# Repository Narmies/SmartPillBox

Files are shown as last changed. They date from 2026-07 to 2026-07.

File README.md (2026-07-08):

# 💊 SimpleMed - Smart Medicine Box (ჭკვიანი წამლების ყუთი)

ეს პროექტი არის ESP32-სა და RTC DS3231 მოდულზე ბაზირებული, ორ სლოტიანი **ჭკვიანი წამლების ყუთი**. მოწყობილობის კონფიგურაცია ხდება მარტივი ვებ-ინტერფეისის საშუალებით და ინტეგრირებული აქვს Telegram შეტყობინებების სისტემა.

## 🚀 ფუნქციები
- **ორენოვანი მხარდაჭერა:** ვებ-ინტერფეისი და Telegram შეტყობინებები მუშაობს როგორც ინგლისურ, ასევე ქართულ ენაზე.
- **სერვო ძრავების უსაფრთხო კონტროლი:** გაჭედვის საწინააღმდეგო სპეციალური კუთხეები ($50^\circ$ და $55^\circ$) და თავსახურის ავტომატური დაკეტვა 120 წამის შემდეგ.
- **RTC DS3231 დროის კონტროლი:** რეალური დროის მოდული, რომელიც ინარჩუნებს დროს დენის გათიშვის შემთხვევაშიც კი.
- **Telegram შეტყობინებები:** შეხსენება წამლის დროის მოსვლისას, დასტური მიღებისას და გაფრთხილება მოულოდნელი გათიშვის (Power Loss) შესახებ.
- **აქტიური განგაში:** წყვეტილი ხმოვანი სიგნალი (Buzzer) და LED ინდიკატორი, რომელიც ითიშება ღილაკზე ხელის დაჭერით.
- **მკურნალობის კურსის ხანგრძლივობა:** დღეების რაოდენობის განსაზღვრა (მაგ. 7 დღის შემდეგ შეხსენებები ავტომატურად ჩერდება).

## 🛠️ საჭირო კომპონენტები
- ESP32 Development Board
- Real Time Clock RTC DS3231 მოდული
- 2x SG90 სერვო ძრავი (თავსახურებისთვის)
- Buzzer (აქტიური ხმოვანი სიგნალი) და LED ნათურა
- Push Button (ღილაკი - Interrupt მხარდაჭერით)

## 📌 პინების განაწილება (Pinout)
- **Buzzer:** Pin 5
- **LED:** Pin 2
- **Button:** Pin 15 (Internal Pull-Up)
- **Servo 1 (სლოტი 1):** Pin 18
- **Servo 2 (სლოტი 2):** Pin 19
- **I2C (RTC მოდულისთვის):** ESP32-ის სტანდარტული SDA/SCL პინები

## 💻 დაყენების ინსტრუქცია
1. გახსენით `firmware/SimpleMed.ino` ფაილი Arduino IDE-ში.
2. დარწმუნდით, რომ დაინსტალირებული გაქვთ შემდეგი ბიბლიოთეკები: `UniversalTelegramBot`, `RTClib`, `ESP32Servo`.
3. კოდში `YOUR_TELEGRAM_BOT_TOKEN_HERE`-ს ნაცვლად ჩაწერეთ თქვენი ბოტის რეალური ტოკენი.
4. ჩატვირთეთ კოდი ESP32-ზე.
5. ტელეფონით ან კომპიუტერით დაუკავშირდით Wi-Fi ქსელს სახელით: **SmartPillBox-Setup**.
6. ბრაუზერში გახსენით მისამართი `192.168.4.1`, აირჩიეთ ენა, მიუთითეთ საათები, თქვენი სახლის Wi-Fi-ს მონაცემები და Telegram Chat ID.

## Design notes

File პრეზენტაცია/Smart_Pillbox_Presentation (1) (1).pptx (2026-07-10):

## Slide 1

CE490B · ილიას სახელმწიფო უნივერსიტეტი · 2026

ჭკვიანი წამლის ყუთი

Smart Pillbox — Automated Medication Reminder System

პრეზენტატორები:
ნარმინ სეიდოვა
ხამმათი აბაზოვი
აინურ ალახვერდიევა

პროექტის ხელმძღვანელები:
დავით ჩხაიძე
გიორგი მოდებაძე

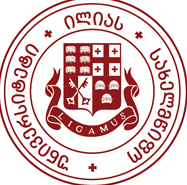
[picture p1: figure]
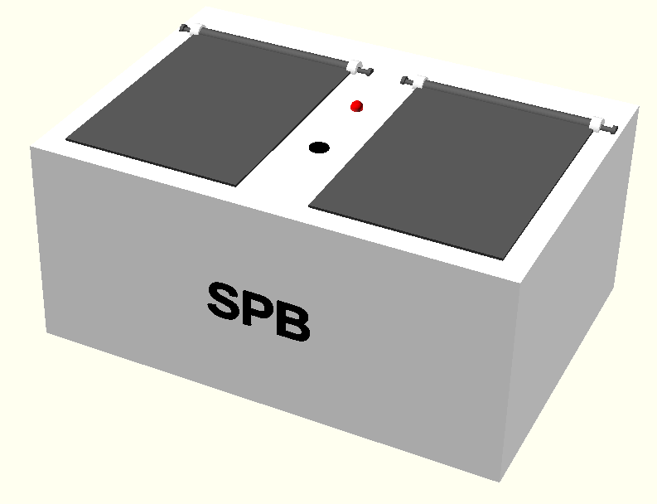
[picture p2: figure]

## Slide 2

პრობლემა

დავიწყება, რომელიც ძვირი უჯდება ჯანმრთელობას

~50%

ქრონიკული დაავადების მქონე პაციენტი არ იცავს პრეპარატის მიღების რეჟიმს.

წყარო: WHO, 2003

35–45%

ხანდაზმულ პაციენტს ავიწყდება ყოველდღიური მედიკამენტის მიღება.

წყარო: WHO, 2003

300–500$

ღირს ბაზარზე არსებული ჭკვიანი დისპენსერი — ხშირად ყოველთვიური საბონენტო გადასახადითურთ.

მაგ. MedMinder Maya, Hero Health

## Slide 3

გადაწყვეტა

ოთხი ფუნქცია, ერთი მარტივი ყუთი

ზუსტი შეხსენება

DS3231 RTC მოდული დროს ინახავს კვების გათიშვის შემთხვევაშიც კი — შეხსენება ირთვება ±1 წამის სიზუსტით.

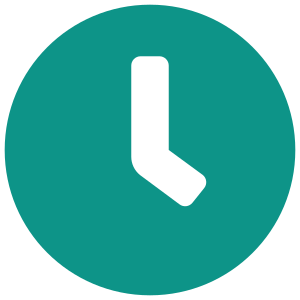
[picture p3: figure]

01

ფიზიკური წვდომა

ღილაკზე დაჭერისას სერვო-მოტორი 45°-ით ხსნის სწორ განყოფილებას — <1 წამში.

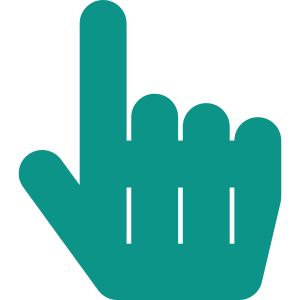
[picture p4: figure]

02

Telegram შეტყობინება

თუ დასტური არ დაფიქსირდა, მომვლელს <3 წამში ეგზავნება გამაფრთხილებელი შეტყობინება.

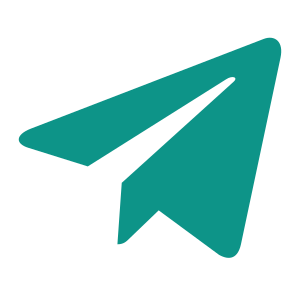
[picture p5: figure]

03

Web კონფიგურაცია

მოწყობილობა თავად ქმნის Wi-Fi ქსელს — გრაფიკის დაყენება ხდება ტელეფონის ბრაუზერიდან, აპლიკაციის გარეშე.

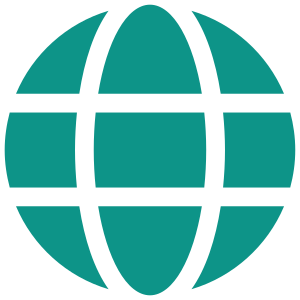
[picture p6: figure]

04

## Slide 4

ინტერფეისი

დაყენება ორ წუთში, აპლიკაციის გარეშე

1

2

01

02

დაუკავშირდით ყუთის ქსელს

მოწყობილობა ჩართვისას თავად ქმნის Wi-Fi ქსელს — „SmartPillBox-Setup“ — ხილვადია ტელეფონის Wi-Fi სიაში.

აირჩიეთ ენა

Web გვერდი იხსნება ავტომატურად (captive portal) და მხარს უჭერს ქართულ და ინგლისურ ენებს.

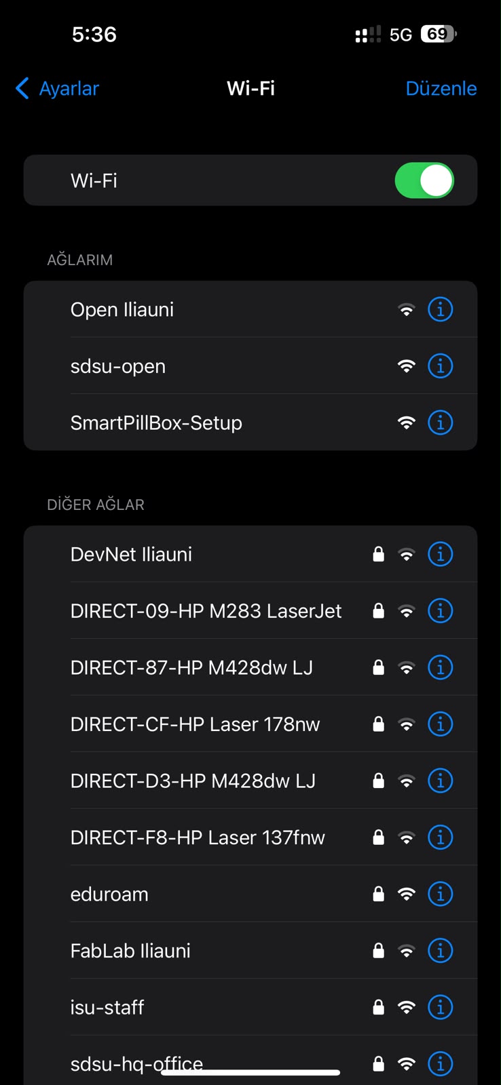
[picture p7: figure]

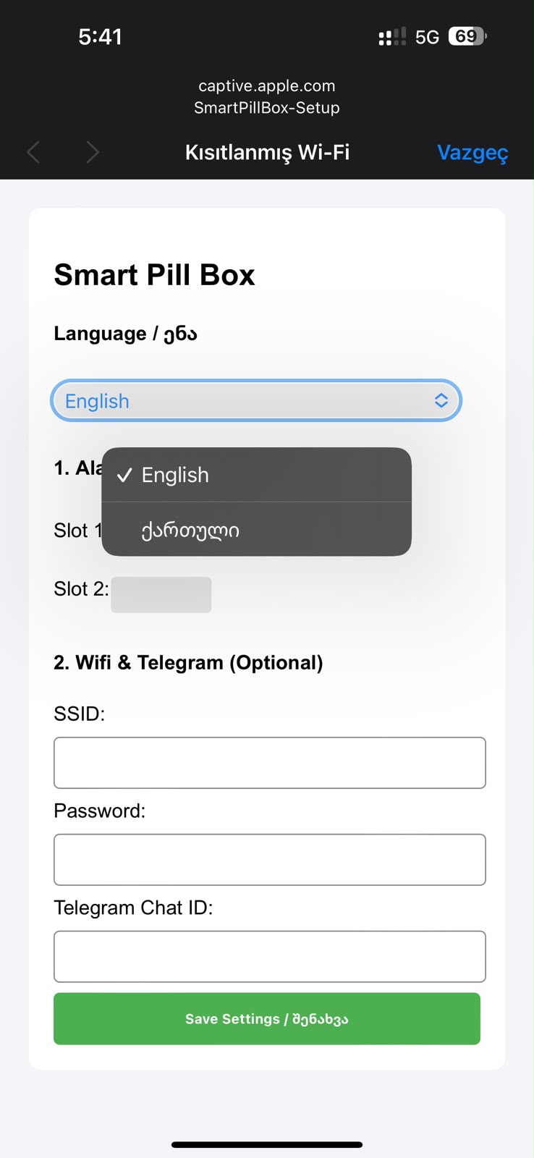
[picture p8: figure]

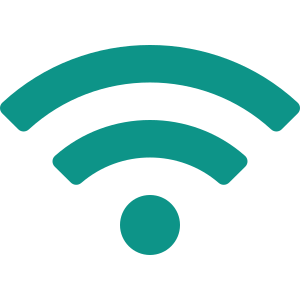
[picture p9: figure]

→

03

04

დააყენეთ დრო და Telegram

შეიყვანეთ ბოლქვის დროის გრაფიკი, სახლის Wi-Fi და Telegram Chat ID მომვლელის შესატყობინებლად.

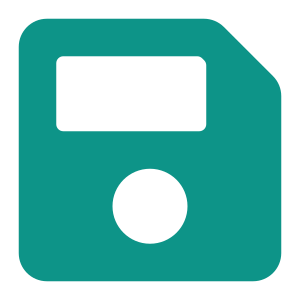
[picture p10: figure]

შეინახეთ და დაივიწყეთ

პარამეტრები ინახება EEPROM-ში და გადარჩება კვების გათიშვის შემთხვევაშიც.

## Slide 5

მუშაობის პრინციპი

ერთი ციკლი, ნაბიჯ-ნაბიჯ

დროის შემოწმება

ESP32 ყოველ წამში კითხულობს დროს DS3231 RTC-იდან (I²C) და ადარებს გრაფიკს.

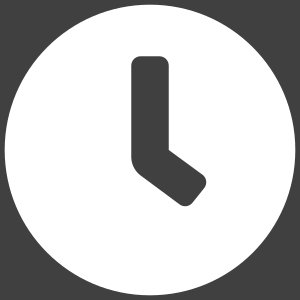
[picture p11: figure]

შეხსენების გააქტიურება

დროის დამთხვევისას ირთვება ხმოვან-ვიზუალური სიგნალი — ბუზერი და წითელი LED.

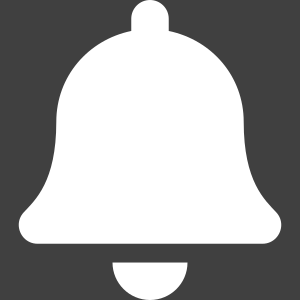
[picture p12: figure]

პაციენტის დასტური

პაციენტი აჭერს ღილაკს, სიგნალი ჩერდება და სერვო ხსნის შესაბამის განყოფილებას.

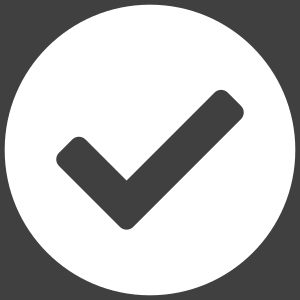
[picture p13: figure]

დასტურის გაცემა

Telegram Bot მომვლელს უგზავნის დადასტურების შეტყობინებას მიღების შესახებ.

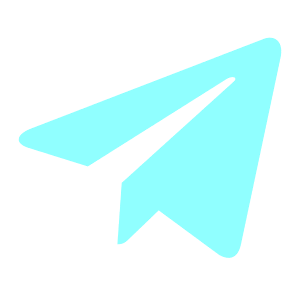
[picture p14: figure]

გამოტოვების შემთხვევა

2 წუთის განმავლობაში დაუდასტურებლობისას სისტემა აგზავნის გამაფრთხილებელ შეტყობინებას.

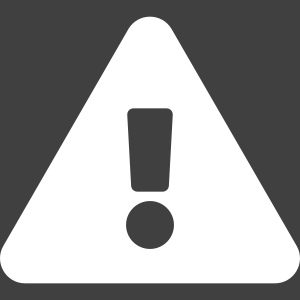
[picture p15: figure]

→

→

→

→

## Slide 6

კომპონენტების ელექტრული შეერთების სქემა

RTC

I²C · SDA/SCL

Buzzer

GPIO 25

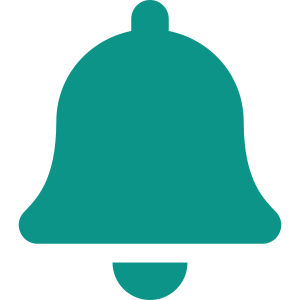
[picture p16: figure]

SG90 სერვო A

DS3231 RTC

GPIO 13 · PWM

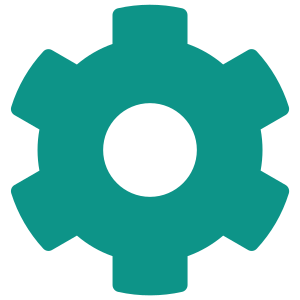
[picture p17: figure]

ESP32 DevKit

38-pin · Dual-core

LED (წითელი)

Buzzer

GPIO 26

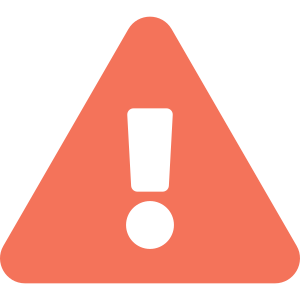
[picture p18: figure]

SG90 სერვო B

GPIO 14 · PWM

Wi-Fi / Telegram

HTTPS Cloud API

Push Button

GPIO 27

5V / 2A კვება

USB Power

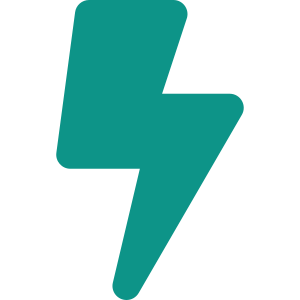
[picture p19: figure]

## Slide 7

საწარმო ნახაზი

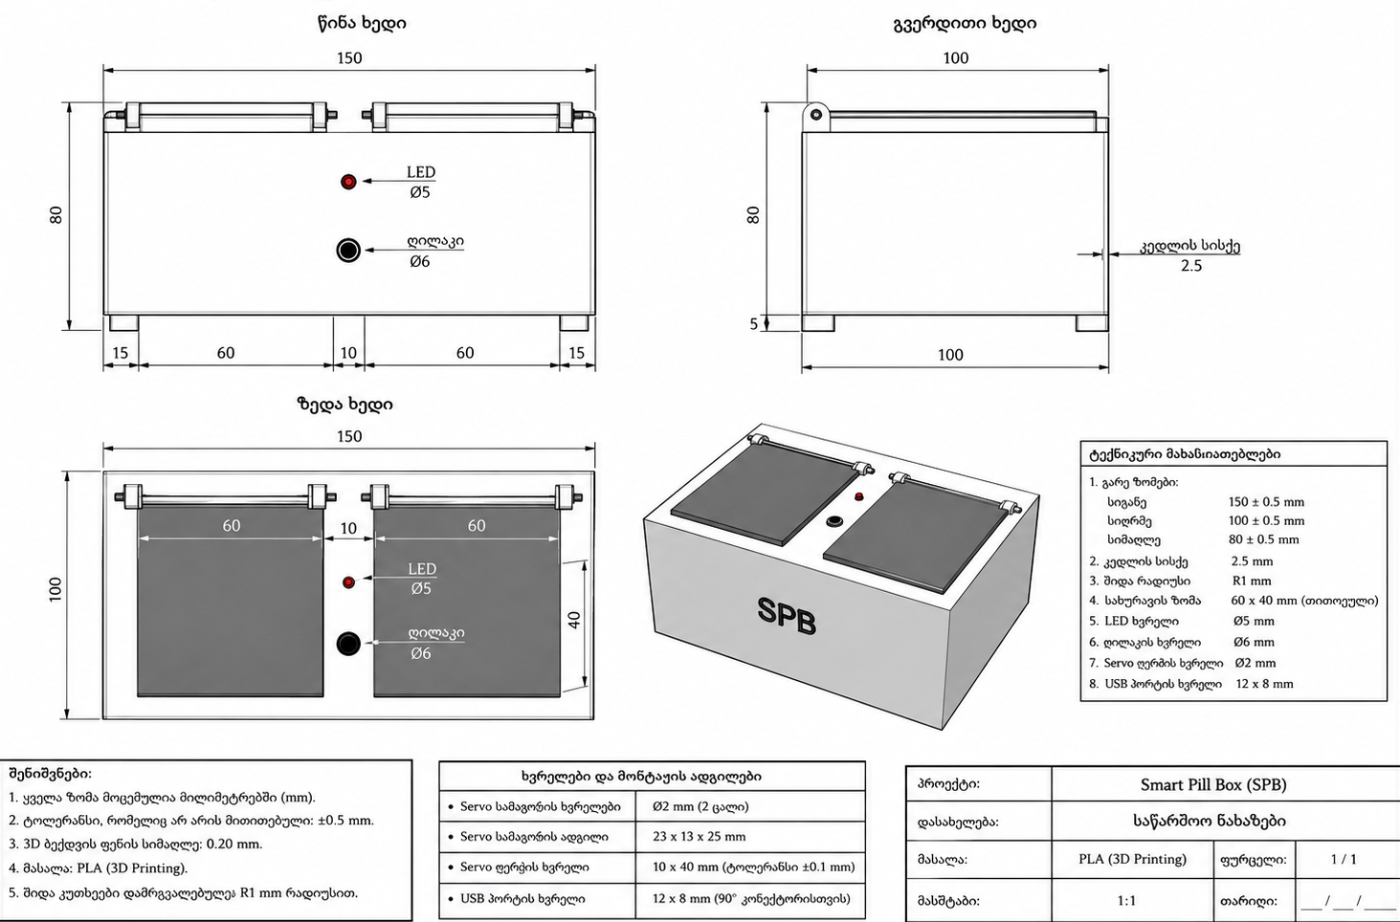
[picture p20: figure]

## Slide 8

გუნდი

CE490B გუნდი

პროექტი განხორციელდა სამკაციანი გუნდის მიერ

ნარმინ სეიდოვა

Lead Software Engineer

ESP32 ფირმვეარისა და არქიტექტურის შემუშავება, Wi-Fi AP კონფიგურაცია, EEPROM ლოგიკა, Web ინტერფეისი და Telegram Bot API ინტეგრაცია. გადაჭრა სერვოს PWM jitter პრობლემა LEDC ტაიმერით.

ხამათი აბაზოვი

Hardware & Prototyping Engineer

კორპუსის 3D მოდელირება და CAD დიზაინი, ელექტრული სქემები და ფიზიკური აწყობა. კვების ბიუჯეტის ანალიზი და პროტოტიპის მექანიკური ტესტირება.

აინურ ალახვერდიევა

Systems Analyst & Documentation Manager

ტექნიკური დოკუმენტაცია, ბლოკ-სქემები და ალგორითმები, ბაზრის ანალიზი, BOM ბიუჯეტი, განტის დიაგრამა, სტანდარტების შესაბამისობა.

ნს

ხა

აა

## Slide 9

SMART PILLBOX

მადლობა ყურადღებისთვის

ნარმინ სეიდოვა · აინურ ალახვერდიევა · ხამათი აბაზოვი

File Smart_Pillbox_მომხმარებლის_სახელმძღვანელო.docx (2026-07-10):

SMARTPILLBOX

ჭკვიანი წამლის ყუთი

მომხმარებლის სახელმძღვანელო

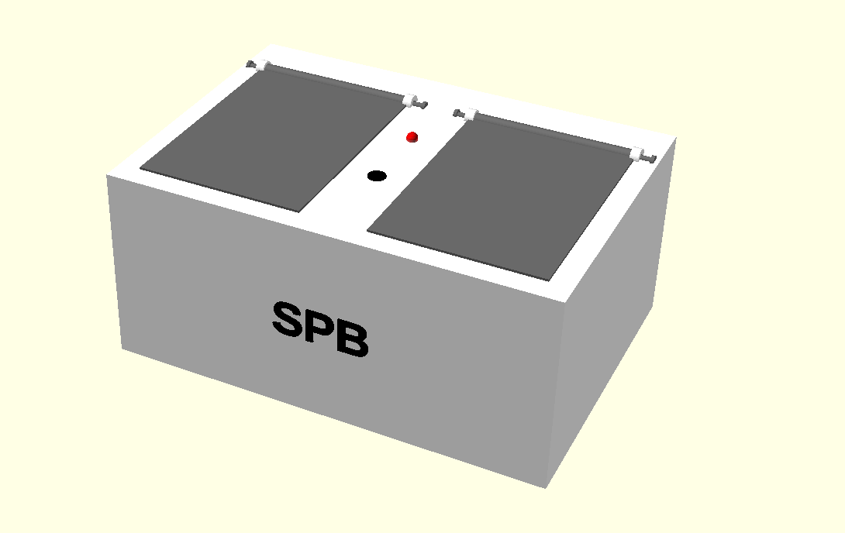
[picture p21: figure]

CE490B — Smart Pillbox (SPB) პროექტი

ილიას სახელმწიფო უნივერსიტეტი, თბილისი, 2026

# 1. შესავალი

Smart Pillbox (SPB) არის ორ-განყოფილებიანი ჭკვიანი წამლის ყუთი, რომელიც შექმნილია მედიკამენტების მიღების გრაფიკის დასაცავად — განსაკუთრებით ხანდაზმული პაციენტებისა და ქრონიკული დაავადებების მქონე პირებისთვის. მოწყობილობა ESP32 მიკროკონტროლერზეა დაფუძნებული და აერთიანებს ოთხ ძირითად ფუნქციას.

- ავტომატური ხმოვანი და ვიზუალური შეხსენება წინასწარ განსაზღვრულ დროს.
- ფიზიკური წვდომის კონტროლი — განყოფილება იხსნება მხოლოდ ღილაკზე დაჭერის შემდეგ.
- Telegram Bot შეტყობინებები მომვლელისთვის — მიღების ან გამოტოვების შესახებ, რეალურ დროში.
- Wi-Fi ვებ-ინტერფეისი გრაფიკის მარტივი კონფიგურაციისთვის, დამატებითი აპლიკაციის გარეშე.

წინამდებარე სახელმძღვანელო გიხსნით მოწყობილობის პირველად გამართვას, ყოველდღიურ გამოყენებას, მოვლას და ხშირად წამოჭრილი პრობლემების მოგვარებას.

# 2. კომპლექტის შემადგენლობა

- Smart Pillbox მოწყობილობა (ორი განყოფილებით)
- 5V / 2A USB კვების ადაპტერი და USB კაბელი

შემოწმებული USB კვების ადაპტერი აუცილებელია სტაბილური მუშაობისთვის — მინიმუმ 5V/2A.

# 3. მოწყობილობის აღწერა

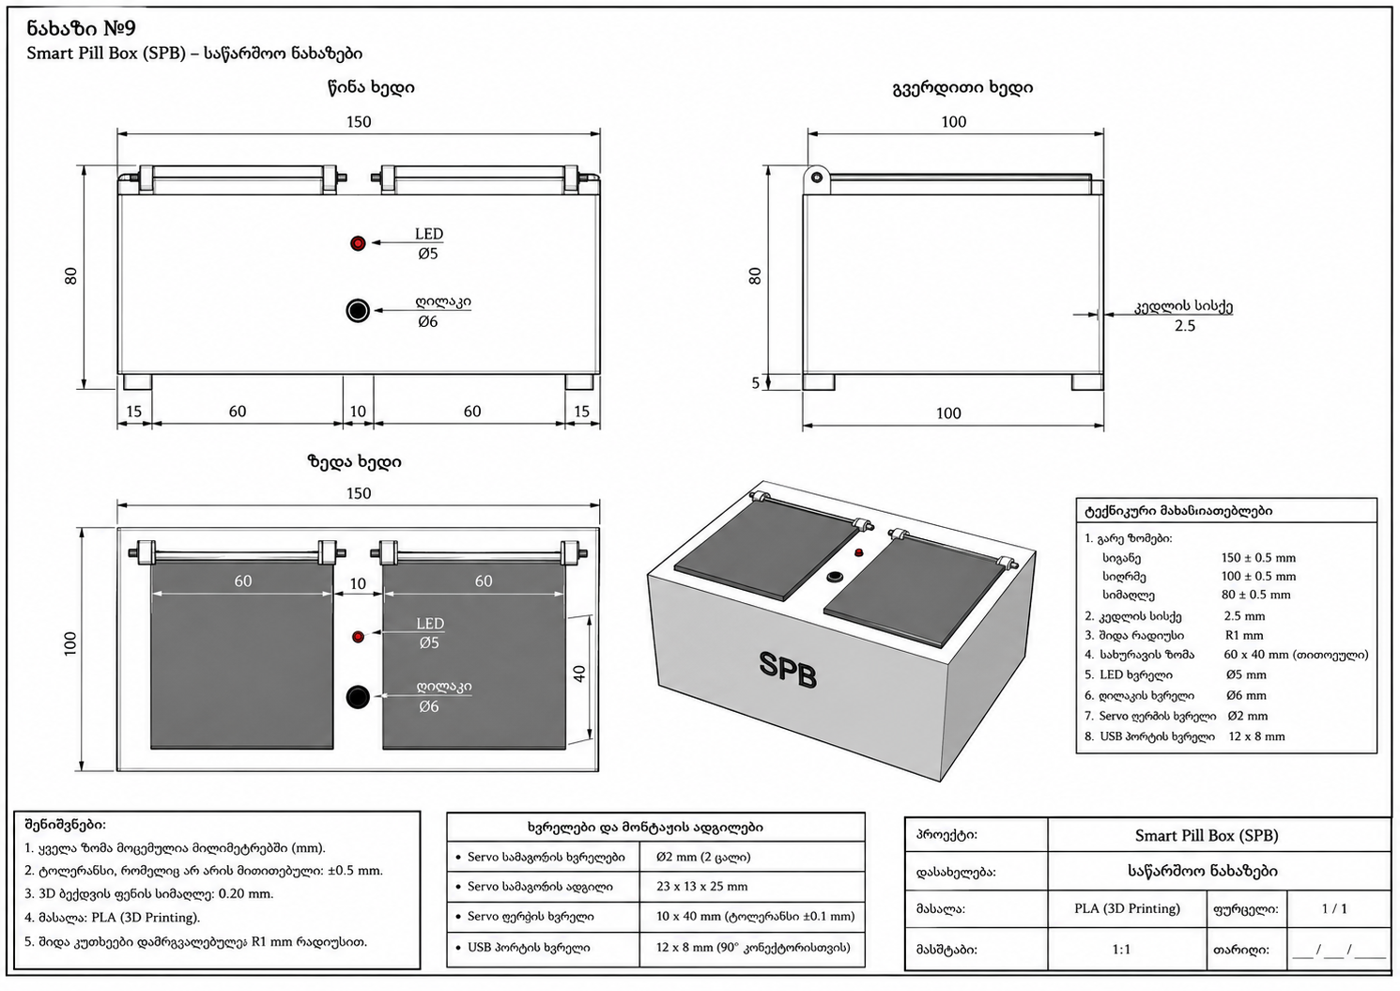
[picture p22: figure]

სურ. 1 — Smart Pillbox-ის კორპუსის აღნაგობა და ზომები

## წინა პანელი

- ორი დახურვადი განყოფილება — მარცხენა (განყოფილება 1) და მარჯვენა (განყოფილება 2), თითოეული საკუთარი სერვო-საკეტით.
- წითელი LED ინდიკატორი — ანთებულია შეხსენების დროს.
- დასტურის ღილაკი — გამოიყენება შეხსენების დასადასტურებლად და გახსნის გასააქტიურებლად.
- ჩაშენებული ხმოვანი სიგნალიზატორი (buzzer) — გაისმის შეხსენების დროს.

## გვერდითი პანელი

- USB კვების პორტი (5V).

# 4. პირველადი გამართვა

## 4.1 კვების მიერთება

1. მიაერთეთ USB კაბელი მოწყობილობასა და 5V/2A ადაპტერს შორის.
2. ჩართეთ ადაპტერი ელქსელში. წამიერად აინთება LED, რაც სისტემის გაშვებას მიანიშნებს.

პირველი ჩართვისას, თუ მოწყობილობას ჯერ არ აქვს შენახული Wi-Fi ქსელის მონაცემები, ის ავტომატურად გადადის კონფიგურაციის რეჟიმში.

## 4.2 დაკავშირება Wi-Fi კონფიგურაციის რეჟიმში

1. თქვენს ტელეფონზე ან კომპიუტერზე გახსენით Wi-Fi ქსელების სია.
2. მოძებნეთ და დაუკავშირდით ქსელს სახელით "SmartPillbox-Setup".
3. დაკავშირების შემდეგ გახსენით ბრაუზერი — კონფიგურაციის გვერდი ავტომატურად უნდა გაიხსნას;

4.3 გრაფიკისა და Telegram-ის მორგება ვებ-გვერდზე

კონფიგურაციის გვერდზე შეავსეთ შემდეგი ველები:

- "განყოფილება 1" — პირველი დოზის მიღების დრო (სთ:წთ).
- "განყოფილება 2" — მეორე დოზის მიღების დრო (სთ:წთ).
- "Telegram" — მომვლელის Chat ID.
1. შევსების შემდეგ დააჭირეთ ღილაკს "შენახვა".
2. მოწყობილობა შეინახავს პარამეტრებს და გადაერთვება ჩვეულებრივ სამუშაო რეჟიმში.

მომხმარებელი Telegram-ში შედის ძიების (Search) განყოფილებაში, ეძებს SmartPillBox ბოტს და აჭერს Start-ს. ამის შემდეგ მოწყობილობის Wi-Fi პარამეტრებში უთითებს სახლის Wi-Fi ქსელის სახელს, პაროლს და საკუთარ Telegram Chat ID-ს.

თუ ეს მონაცემები შეიყვანს, SmartPillBox დაუკავშირდება ინტერნეტს და Telegram-ის საშუალებით მომხმარებელს გაუგზავნის შეტყობინებებს წამლის მიღების დროისა და სხვა მოვლენების შესახებ.

თუ მომხმარებელი Wi-Fi-ს ან Telegram Chat ID-ს არ შეიყვანს, მოწყობილობა მაინც სრულად ფუნქციონირებს ლოკალურ რეჟიმში (Local Mode). ამ შემთხვევაში წამლის შეხსენებები განხორციელდება მხოლოდ თავად მოწყობილობაზე (ხმოვანი ან ვიზუალური სიგნალებით), ხოლო Telegram-ზე შეტყობინებები არ გაიგზავნება და ინტერნეტთან კავშირი საჭირო არ იქნება.

## 4.4 სახლის Wi-Fi ქსელთან დაკავშირება

იმ შემთხვევაში, თუ მოწყობილობას სურთ სახლის ინტერნეტ ქსელთან დაკავშირება (საჭიროა Telegram შეტყობინებებისთვის), საკონფიგურაციო გვერდზე მიუთითეთ სახლის Wi-Fi ქსელის სახელი (SSID) და პაროლი. ამის შემდეგ მოწყობილობა გადაირთვება მითითებულ ქსელზე და აღარ გაააქტიურებს კონფიგურაციის Access Point-ს ხელახლა ჩართვისას, სანამ შენახული ქსელი ხელმისაწვდომია.

# 5. ყოველდღიური გამოყენება

გრაფიკის კონფიგურაციის შემდეგ მოწყობილობა მუშაობს ავტომატურად. მოქმედების ციკლი შემდეგნაირად მიმდინარეობს:

1. მოწყობილობა უწყვეტად ადარებს მიმდინარე დროს შენახულ გრაფიკს.
2. დანიშნულ დროს ირთვება ხმოვანი სიგნალი და ციმციმებს წითელი LED.
3. დააჭირეთ დასტურის ღილაკს — ეს ადასტურებს, რომ თქვენ მზად ხართ მედიკამენტის მისაღებად.
4. შესაბამისი განყოფილების სერვო-საკეტი იხსნება (~1 წამში) და შეგიძლიათ ამოიღოთ მედიკამენტი.
5. 2 წუთის შემდეგ განყოფილება ავტომატურად იკეტება ხელახლა.
6. წარმატებული მიღების შესახებ Telegram შეტყობინება ეგზავნება მომვლელს.

თუ ღილაკზე დაჭერა არ მოხდა 2 წუთის განმავლობაში, სისტემა თვლის, რომ დოზა გამოტოვებულია, გამოთიშავს ხმოვან სიგნალს და მომვლელს უგზავნის გამაფრთხილებელ შეტყობინებას.

## Telegram შეტყობინებების სახეები

- სისტემის გაშვება — იგზავნება მოწყობილობის ჩართვისას ან გადატვირთვისას.
- წამლის მიღება — იგზავნება პაციენტის მიერ ღილაკზე დაჭერის შემდეგ.
- დოზის გამოტოვება — იგზავნება, თუ 2 წუთის განმავლობაში დასტური არ მოხდა.

# 6. მოვლა და შენახვა

ინტერვალი | სამუშაო
ყოველი 3 თვე | დასტურის ღილაკის ტესტირება ვებ-ინტერფეისიდან.
ყოველი 6 თვე | სერვო-მოტორის რეაგირების დროის შემოწმება — შენელება მიანიშნებს ცვეთაზე.
წელიწადში ერთხელ | RTC საათის სინქრონიზაცია Wi-Fi NTP-ის საშუალებით (საკმარისია ინტერნეტთან დაკავშირება).

კორპუსის გასუფთავებას მოახდინეთ მშრალი ან ოდნავ ნესტიანი ქსოვილით. მოერიდეთ სითხის პირდაპირ დასხმას მოწყობილობაზე.

# 7. ხშირად წამოჭრილი პრობლემები

პრობლემა | შესაძლო მიზეზი | გადაწყვეტა
ხმოვანი სიგნალი სუსტია | დაბალი PWM დონე | მიმართეთ ტექნიკურ მხარდაჭერას firmware-ის პარამეტრის კორექციისთვის.
სერვო-მოტორი ვიბრირებს გახსნისას | ძაბვის მცირე ვარდნა კვების ჩართვის დროს | დარწმუნდით, რომ იყენებთ 5V/2A (არა უფრო სუსტ) ადაპტერს.
Telegram შეტყობინება იგვიანებს ან არ მოდის | სუსტი Wi-Fi სიგნალი ან არასწორი ტოკენი | დაარეგისტრირეთ მოწყობილობა როუტერთან უფრო ახლოს; გადაამოწმეთ Telegram ტოკენი კონფიგურაციის გვერდზე.
დაზოგილი გრაფიკი დაიკარგა | მოწყობილობა არ იყო გამორთული სწორად კვების პროცესში | გრაფიკი ავტომატურად ინახება EEPROM-ში — ხელახლა შეიყვანეთ გრაფიკი ვებ-გვერდიდან.
ვერ ვუკავშირდები SmartPillbox-Setup ქსელს | მოწყობილობას უკვე აქვს შენახული სახლის Wi-Fi | დააჭირეთ და დაიჭირეთ დასტურის ღილაკი 5 წამის განმავლობაში კონფიგურაციის რეჟიმის ხელახლა გასააქტიურებლად.

# 8. უსაფრთხოების ინსტრუქციები

- გამოიყენეთ მხოლოდ თანდართული ან შესაბამისი 5V/2A CE-სერტიფიცირებული USB ადაპტერი.
- არ ჩაუშვათ მოწყობილობა წყალში და არ დატოვოთ ტენიან გარემოში.
- არ ცადოთ სერვოს მექანიზმის ხელით გატეხვა ან ძალდატანებით გახსნა. ამან შესაძლოა დააზიანოს მექანიზმი.
- მოწყობილობა განკუთვნილია მხოლოდ საშინაო, სტაციონარულ გამოყენებისთვის ოთახის ტემპერატურაზე.

9. ტექნიკური მახასიათებლები

პარამეტრი | მნიშვნელობა
მიკროკონტროლერი | ESP32 (ორბირთვიანი, ჩაშენებული Wi-Fi)
საათის მოდული | DS3231 RTC (±2 ppm სიზუსტე)
გახსნის მექანიზმი | SG90 სერვო-მოტორი ×2 (45° ბრუნვა)
კვება | 5V / 2A USB ადაპტერი (SELV)
კავშირი | Wi-Fi 2.4 GHz (IEEE 802.11), Access Point ან სახლის ქსელი
შეტყობინებები | Telegram Bot API (HTTPS)
გარეთა ზომები | 150 × 100 × 80 მმ (±0.5 მმ)
კორპუსის მასალა | PLA (3D ბეჭდვა)
შეხსენების სიზუსტე | ±1 წამი
გახსნის რეაგირების დრო | < 1 წამი
Telegram შეტყობინების დაყოვნება | < 3 წამი

# 10. მხარდაჭერა

პროექტის სრული საწყისი კოდი, ნახაზები და დამატებითი მასალები ხელმისაწვდომია პროექტის GitHub რეპოზიტორიაში:

GitHub Link (https://github.com/Narmies/SmartPillBox)

Smart Pillbox — მომხმარებლის სახელმძღვანელო

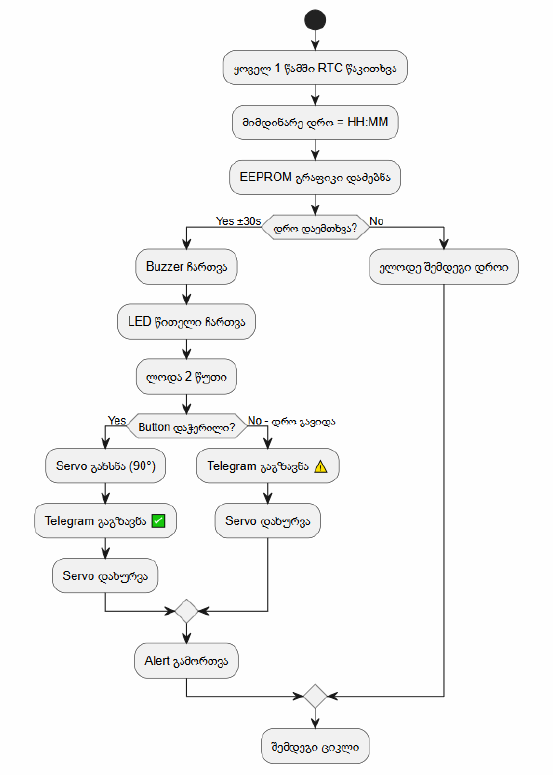
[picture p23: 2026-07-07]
ნახაზები/მთავარი Loop ალგორითმი.png

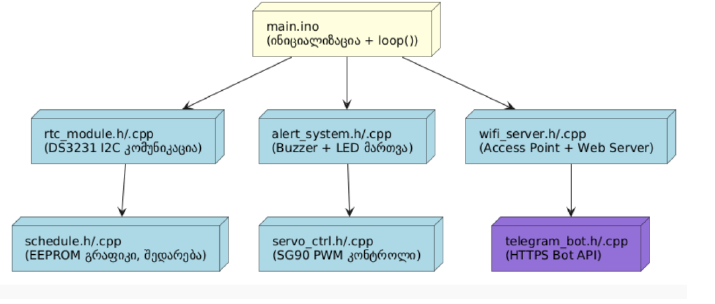
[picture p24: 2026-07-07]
ნახაზები/ფირმვეარის მოდულური არქიტექტურა.png

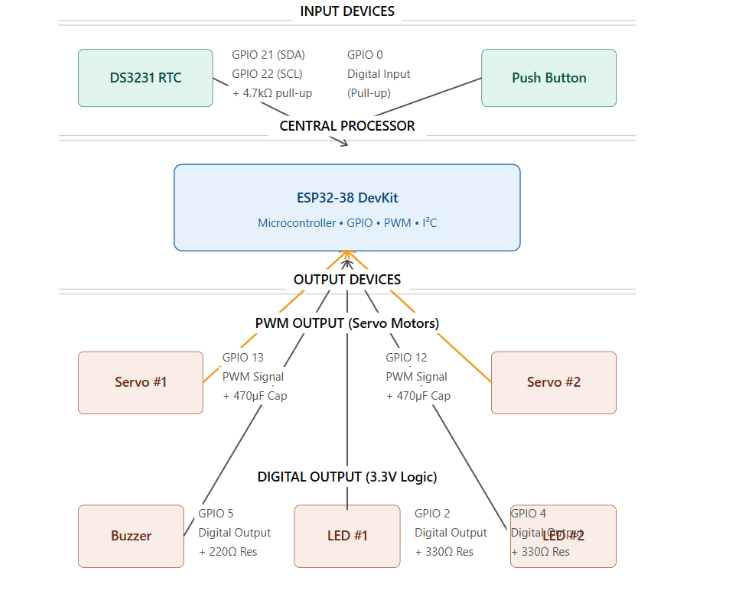
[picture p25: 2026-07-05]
ნახაზები/კომპონენტების შეერთების სქემა.png

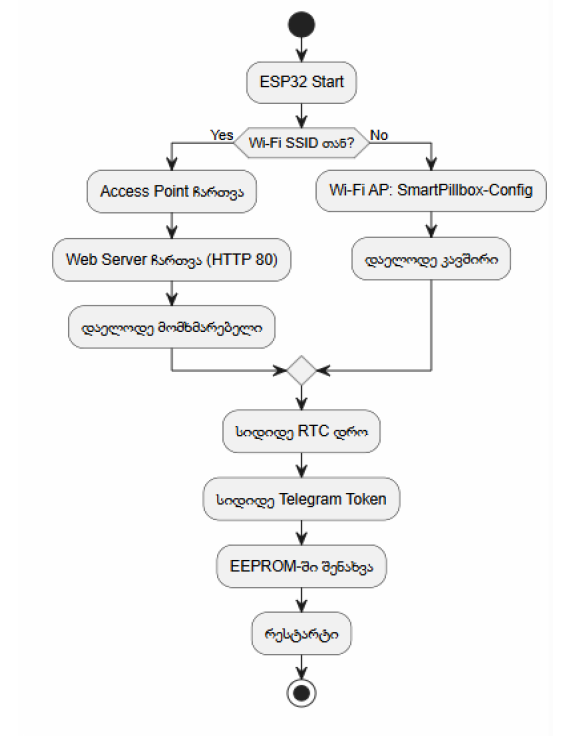
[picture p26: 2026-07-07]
ნახაზები/Wi-Fi კონფიგურაციის ფლოუ-ჩარტი.png

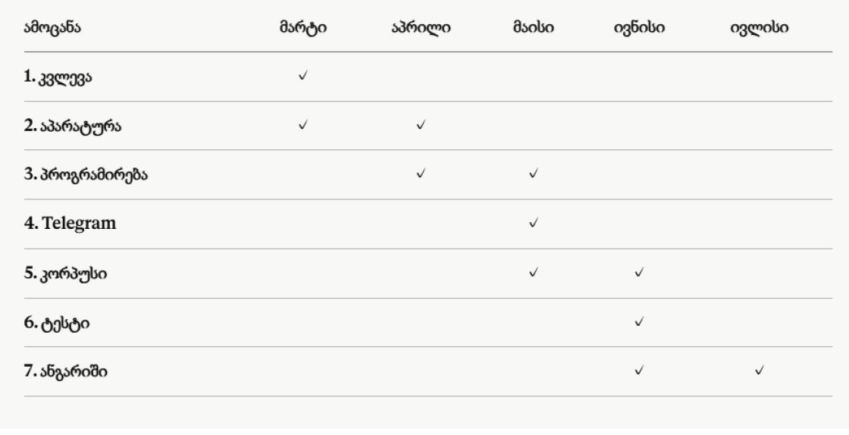
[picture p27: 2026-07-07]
ცხრილები/განტის დიაგრამა.png

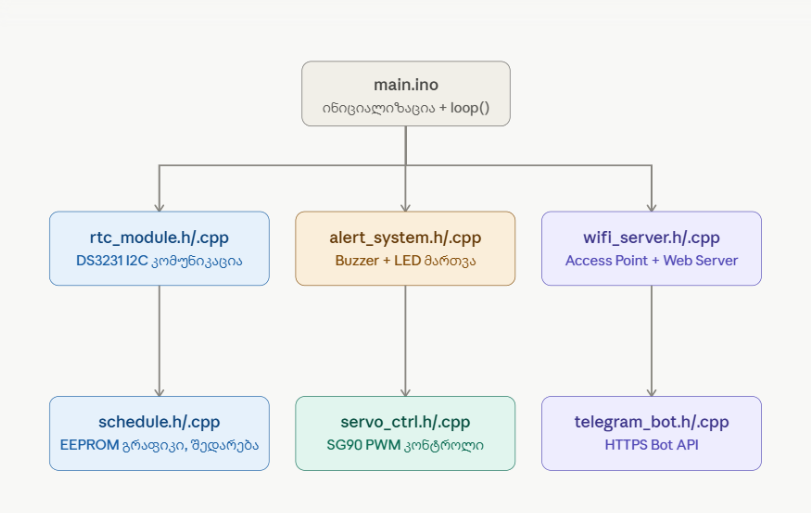
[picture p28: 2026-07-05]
ნახაზები/ფირმვეარის მოდულური არქიტექტურა .png

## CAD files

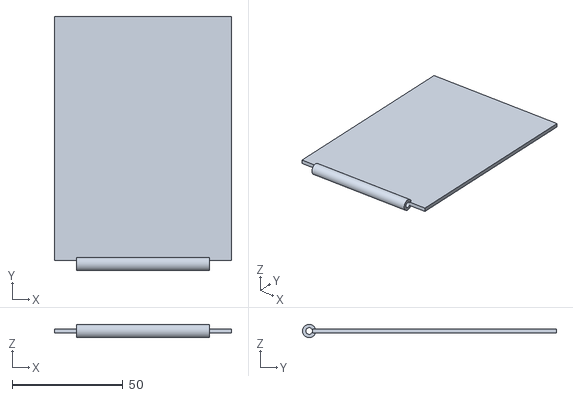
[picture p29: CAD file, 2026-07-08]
OpenScad/lid.stl
80.0 x 114.5 x 6.00

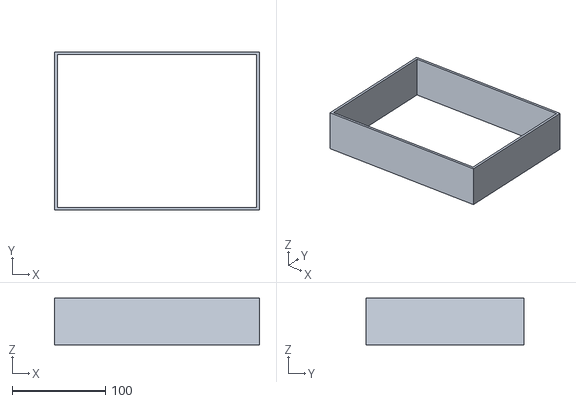
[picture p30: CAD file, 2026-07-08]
OpenScad/gverdi.stl
220.0 x 170.0 x 50.0

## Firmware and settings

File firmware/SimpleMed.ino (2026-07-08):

#include <WiFi.h>

#include <WebServer.h>

#include <DNSServer.h>

#include <RTClib.h>

#include <ESP32Servo.h>

#include <WiFiClientSecure.h>

#include <UniversalTelegramBot.h>

#include <Preferences.h>

#include <esp_system.h>

#include <time.h>

#include "soc/soc.h"

#include "soc/rtc_cntl_reg.h"



RTC_DS3231 rtc;

bool rtc_ok = false;



Servo servo1;

Servo servo2;



WebServer server(80);

DNSServer dnsServer;

const byte DNS_PORT = 53;



Preferences prefs;



int slot1_hour = 0, slot1_minute = 0;

int slot2_hour = 0, slot2_minute = 0;

bool slot1_configured = false;

bool slot2_configured = false;



String home_ssid = "";

String home_pass = "";

String telegram_chat_id = "";

bool telegram_active = false;




int duration_days = 0;

int elapsed_days = 0;

int last_seen_day = -1; 




String lang = "en";



#ifndef BOT_TOKEN

#define BOT_TOKEN "YOUR_TELEGRAM_BOT_TOKEN_HERE"

#endif

const char* botToken = BOT_TOKEN;



WiFiClientSecure secured_client;

UniversalTelegramBot bot(botToken, secured_client);



#define BUZZER 5

#define LED    2

#define BUTTON 15



bool slot1_alarm  = false;

bool slot2_alarm  = false;

bool slot1_taken = false;

bool slot2_taken = false;



unsigned long lastCheck = 0;

unsigned long slot1_open_time = 0;

unsigned long slot2_open_time = 0;



bool slot1_lid_open_waiting = false;

bool slot2_lid_open_waiting = false;



bool setup_phase_active = true;

bool lids_opened_for_setup = false;



bool internet_connect_request = false;

bool wifi_connecting = false;

int wifi_connect_attempts = 0;

const int WIFI_MAX_ATTEMPTS = 240; 

const unsigned long WIFI_RETRY_STEP_MS = 500;

unsigned long lastWifiAttemptTick = 0;



bool pending_connect_message = false;

bool pending_power_loss_message = false;

bool pending_ready_message = false;

bool pending_finished_message = false;




volatile bool buttonPressedFlag = false;

unsigned long lastInterruptTime = 0;



void IRAM_ATTR buttonISR() {

  unsigned long interruptTime = millis();

  if (interruptTime - lastInterruptTime > 250) {

    buttonPressedFlag = true;

    lastInterruptTime = interruptTime;

  }

}



// Buzzer 

bool buzzer_active = false;

unsigned long lastBuzzerToggle = 0;

const unsigned long BUZZER_ON_MS  = 300;

const unsigned long BUZZER_OFF_MS = 200;

bool buzzer_pin_state = false;



void updateBuzzer() {

  if (!buzzer_active) {

    digitalWrite(BUZZER, LOW);

    buzzer_pin_state = false;

    return;

  }

  unsigned long now = millis();

  unsigned long currentInterval = buzzer_pin_state ? BUZZER_ON_MS : BUZZER_OFF_MS;

  if (now - lastBuzzerToggle >= currentInterval) {

    buzzer_pin_state = !buzzer_pin_state;

    digitalWrite(BUZZER, buzzer_pin_state ? HIGH : LOW);

    lastBuzzerToggle = now;

  }

}



void startBuzzer() {

  if (!buzzer_active) {

    buzzer_active = true;

    buzzer_pin_state = true;

    digitalWrite(BUZZER, HIGH);

    lastBuzzerToggle = millis();

  }

}



void stopBuzzerHard() {

  buzzer_active = false;

  buzzer_pin_state = false;

  digitalWrite(BUZZER, LOW);

}



//  "biip"

void startupBeep() {

  digitalWrite(BUZZER, HIGH);

  delay(150);

  digitalWrite(BUZZER, LOW);

}





String tr_ready(int h1, int m1, int h2, int m2, int days) {

  char buf1[6], buf2[6];

  sprintf(buf1, "%02d:%02d", h1, m1);

  sprintf(buf2, "%02d:%02d", h2, m2);

  String daysTxt;

  if (lang == "ka") {

    daysTxt = (days > 0) ? (String(days) + " დღე") : "განუსაზღვრელი ვადით";

    return "✅ Smart Pill Box მზადაა!\nსლოტი 1: " + String(buf1) + "\nსლოტი 2: " + String(buf2) + "\nხანგრძლივობა: " + daysTxt;

  }

  daysTxt = (days > 0) ? (String(days) + " days") : "unlimited";

  return "✅ Smart Pill Box is ready!\nSlot 1: " + String(buf1) + "\nSlot 2: " + String(buf2) + "\nDuration: " + daysTxt;

}



String tr_connected() {

  if (lang == "ka") return "🚀 Smart Pill Box ინტერნეტს დაუკავშირდა!";

  return "🚀 Smart Pill Box connected to the internet!";

}



String tr_taken(int slot) {

  if (lang == "ka") return "✅ მედიკამენტი მიღებულია: სლოტი " + String(slot) + ".";

  return "✅ Medication taken: Slot " + String(slot) + ".";

}



String tr_alert(int slot) {

  if (lang == "ka") return "🚨 გაფრთხილება: სლოტი " + String(slot) + " დროა!";

  return "🚨 ALERT: Slot " + String(slot) + " medication time has arrived!";

}



String tr_power_loss() {

  if (lang == "ka") return "⚠️ ყურადღება: შესაძლოა მოხდა დენის გათიშვა ან ვარდნა. მოწყობილობა გადაიტვირთა.";

  return "⚠️ Warning: A power interruption or voltage drop may have occurred. The device restarted.";

}



String tr_finished() {

  if (lang == "ka") return "🏁 მკურნალობის კურსი დასრულდა. შეხსენებები გაჩერდა.";

  return "🏁 The medication course has finished. Reminders have stopped.";

}



//  Web 

void handleRoot() {

  Serial.println("[SYSTEM] Sending web interface.");




  if (!lids_opened_for_setup) {

    lids_opened_for_setup = true;

    

    Serial.println("[KAPAK] Arayuze baglanildi. Servolar sirayla aciliyor...");

    servo1.attach(18, 500, 2400); 

    servo1.write(50); 

    delay(400); 

    

    servo2.attach(19, 500, 2400); 

    servo2.write(50); 

  }



  String html = "<!DOCTYPE html><html><head><meta charset='UTF-8'><meta name='viewport' content='width=device-width, initial-scale=1'>";

  html += "<style>body{font-family:Arial; text-align:center; background:#f4f4f9; padding:15px;} .container{background:white; padding:20px; border-radius:10px; max-width:420px; margin:auto; text-align:left;} input,select{font-size:16px; padding:10px; margin:8px 0; width:95%;} button{background:#4CAF50; color:white; padding:14px; border:none; border-radius:5px; width:100%; font-weight:bold; cursor:pointer;}</style>";

  html += "<script>function sendTime(){ var d = new Date(); document.getElementById('phone_time').value = d.getHours() + ':' + d.getMinutes() + ':' + d.getSeconds(); }</script></head>";

  html += "<body><div class='container'><h2>Smart Pill Box</h2><form action='/save' method='GET' onsubmit='sendTime()'>";

  html += "<h4>Language / ენა</h4><select name='lang'><option value='en'>English</option><option value='ka'>ქართული</option></select><br>";

  html += "<h4>1. Alarm Times / დროები</h4><label>Slot 1:</label><input type='time' name='b1' required><br><label>Slot 2:</label><input type='time' name='b2' required><br>";

  html += "<h4>2. Duration / ხანგრძლივობა</h4><label>Days (0 = unlimited / შეუზღუდავი):</label><input type='number' name='days' min='0' value='0'><br>";

  html += "<h4>3. Wifi & Telegram (Optional)</h4><label>SSID:</label><input type='text' name='wifi_ssid'><br><label>Password:</label><input type='password' name='wifi_pass'><br><label>Telegram Chat ID:</label><input type='text' name='chat_id'><br>";

  html += "<input type='hidden' id='phone_time' name='t_time'><button type='submit'>Save Settings / შენახვა</button></form></div></body></html>";

  server.send(200, "text/html; charset=UTF-8", html);

}



void handleSave() {

  if (server.hasArg("b1") && server.hasArg("b2")) {



    if (server.hasArg("lang")) {

      lang = server.arg("lang");

      if (lang != "ka") lang = "en";

      prefs.putString("lang", lang);

    }



    slot1_hour = server.arg("b1").substring(0, 2).toInt();

    slot1_minute = server.arg("b1").substring(3, 5).toInt();

    slot1_configured = true; slot1_taken = false;



    slot2_hour = server.arg("b2").substring(0, 2).toInt();

    slot2_minute = server.arg("b2").substring(3, 5).toInt();

    slot2_configured = true; slot2_taken = false;



    duration_days = server.hasArg("days") ? server.arg("days").toInt() : 0;

    if (duration_days < 0) duration_days = 0;

    elapsed_days = 0;

    last_seen_day = -1;




    servo1.write(5); delay(300); servo2.write(5);

    setup_phase_active = false;



    if (server.hasArg("t_time") && rtc_ok) {

      String t_time = server.arg("t_time");

      int t_h = t_time.substring(0, t_time.indexOf(':')).toInt();

      int t_m = t_time.substring(t_time.indexOf(':') + 1, t_time.lastIndexOf(':')).toInt();

      int t_s = t_time.substring(t_time.lastIndexOf(':') + 1).toInt();

      DateTime now = rtc.now();

      rtc.adjust(DateTime(now.year(), now.month(), now.day(), t_h, t_m, t_s));

      last_seen_day = now.day();

    }



    home_ssid = server.arg("wifi_ssid");

    home_pass = server.arg("wifi_pass");

    telegram_chat_id = server.arg("chat_id");



    prefs.putInt("s1h", slot1_hour); prefs.putInt("s1m", slot1_minute);

    prefs.putInt("s2h", slot2_hour); prefs.putInt("s2m", slot2_minute);

    prefs.putBool("s1cfg", true); prefs.putBool("s2cfg", true);

    prefs.putInt("durdays", duration_days);

    prefs.putInt("elapdays", elapsed_days);

    prefs.putInt("lastday", last_seen_day);

    prefs.putString("ssid", home_ssid);

    prefs.putString("pass", home_pass);

    prefs.putString("chatid", telegram_chat_id);



    String msg = "";

    if (home_ssid.length() > 0 && telegram_chat_id.length() > 0) {

      telegram_active = true;

      prefs.putBool("tg_on", true);

      internet_connect_request = true;

      pending_ready_message = true;

      msg = (lang == "ka") ? "<p>ინტერნეტთან დაკავშირება...</p>" : "<p>Connecting to internet...</p>";

    } else {

      telegram_active = false;

      prefs.putBool("tg_on", false);

      msg = (lang == "ka") ? "<p>ჩართულია <b>ლოკალურ რეჟიმში</b>.</p>" : "<p>Started in <b>Local Mode</b>.</p>";

    }



    String response = "<html><body style='text-align:center; font-family:Arial; margin-top:50px;'><h2>✅ Saved!</h2>" + msg + "</body></html>";

    server.send(200, "text/html; charset=UTF-8", response);

  }

}



bool sendTelegramReliable(const String &message) {

  if (!telegram_active || WiFi.status() != WL_CONNECTED) {

    Serial.println("[TELEGRAM] Aborted: Wifi not connected or Telegram inactive.");

    return false;

  }



  digitalWrite(BUZZER, LOW);

  Serial.print("[TELEGRAM] Trying to send: "); Serial.println(message);

  bool ok = bot.sendMessage(telegram_chat_id, message, "");



  if (!ok) {

    Serial.println("[TELEGRAM] First attempt failed. Retrying in 1 second...");

    delay(1000);

    ok = bot.sendMessage(telegram_chat_id, message, "");

  }



  if (ok) {

    Serial.println("[TELEGRAM] Sent successfully!");

  } else {

    Serial.println("[TELEGRAM] ERROR: Could not send message.");

  }



  lastBuzzerToggle = millis();

  return ok;

}



void setup() {

  WRITE_PERI_REG(RTC_CNTL_BROWN_OUT_REG, 0);



  Serial.begin(115200);

  delay(500);

  Serial.println("\n=== SYSTEM STARTING ===");



  esp_reset_reason_t reason = esp_reset_reason();

  bool unexpected_restart = (reason != ESP_RST_POWERON && reason != ESP_RST_SW);



  pinMode(BUZZER, OUTPUT);

  pinMode(LED, OUTPUT);



  pinMode(BUTTON, INPUT_PULLUP);

  attachInterrupt(digitalPinToInterrupt(BUTTON), buttonISR, FALLING);



  digitalWrite(BUZZER, LOW);

  digitalWrite(LED, LOW);




  startupBeep();



  prefs.begin("pillbox", false);

  lang = prefs.getString("lang", "en");

  slot1_hour = prefs.getInt("s1h", 0);

  slot1_minute = prefs.getInt("s1m", 0);

  slot2_hour = prefs.getInt("s2h", 0);

  slot2_minute = prefs.getInt("s2m", 0);

  slot1_configured = prefs.getBool("s1cfg", false);

  slot2_configured = prefs.getBool("s2cfg", false);

  duration_days = prefs.getInt("durdays", 0);

  elapsed_days = prefs.getInt("elapdays", 0);

  last_seen_day = prefs.getInt("lastday", -1);

  home_ssid = prefs.getString("ssid", "");

  home_pass = prefs.getString("pass", "");

  telegram_chat_id = prefs.getString("chatid", "");

  telegram_active = prefs.getBool("tg_on", false);



  if (slot1_configured || slot2_configured) {

    setup_phase_active = false; 


    servo1.attach(18, 500, 2400); servo1.write(5); delay(150);

    servo2.attach(19, 500, 2400); servo2.write(5);

  }



  IPAddress local_IP(192, 168, 4, 1);

  IPAddress gateway(192, 168, 4, 1);

  IPAddress subnet(255, 255, 255, 0);



  WiFi.mode(WIFI_AP);

  WiFi.softAPConfig(local_IP, gateway, subnet);

  WiFi.softAP("SmartPillBox-Setup");



  dnsServer.start(DNS_PORT, "*", local_IP);

  server.on("/", handleRoot);

  server.on("/save", handleSave);

  server.onNotFound(handleRoot);

  server.begin();



  secured_client.setInsecure();



  if (!rtc.begin()) {

    Serial.println("[ERROR] RTC module not found!");

    rtc_ok = false;

  } else {

    rtc_ok = true;

  }



  if (unexpected_restart && telegram_active && home_ssid.length() > 0) {

    Serial.println("[SYSTEM] Unexpected restart detected.");

    internet_connect_request = true;

    pending_power_loss_message = true;

  }

}



void loop() {

  dnsServer.processNextRequest();

  server.handleClient();

  updateBuzzer();



  if (internet_connect_request) {

    internet_connect_request = false;

    Serial.println("[WIFI] Connecting to router...");

    WiFi.mode(WIFI_AP_STA);

    WiFi.begin(home_ssid.c_str(), home_pass.c_str());

    wifi_connecting = true;

    wifi_connect_attempts = 0;

    lastWifiAttemptTick = millis();

  }



  if (wifi_connecting) {

    if (WiFi.status() == WL_CONNECTED) {

      wifi_connecting = false;

      Serial.println("[SYSTEM] Wifi Connected. Syncing time...");

      configTime(0, 0, "pool.ntp.org", "time.nist.gov");



      time_t now = time(nullptr);

      int timeout_cnt = 0;

      while (now < 24 * 3600 && timeout_cnt < 20) {

        delay(500);

        now = time(nullptr);

        timeout_cnt++;

      }

      pending_connect_message = true;

    } else if (millis() - lastWifiAttemptTick >= WIFI_RETRY_STEP_MS) {

      lastWifiAttemptTick = millis();

      wifi_connect_attempts++;

      if (wifi_connect_attempts >= WIFI_MAX_ATTEMPTS) {

        wifi_connecting = false;

        WiFi.mode(WIFI_AP);

        Serial.println("[WIFI] Connection Timeout.");

      }

    }

  }



  if (pending_connect_message && WiFi.status() == WL_CONNECTED) {

    pending_connect_message = false;

    sendTelegramReliable(tr_connected());

  }



  if (pending_ready_message && WiFi.status() == WL_CONNECTED) {

    pending_ready_message = false;

    sendTelegramReliable(tr_ready(slot1_hour, slot1_minute, slot2_hour, slot2_minute, duration_days));

  }



  if (pending_power_loss_message && WiFi.status() == WL_CONNECTED) {

    pending_power_loss_message = false;

    sendTelegramReliable(tr_power_loss());

  }



  if (pending_finished_message && WiFi.status() == WL_CONNECTED) {

    pending_finished_message = false;

    sendTelegramReliable(tr_finished());

  }




  if (buttonPressedFlag) {

    buttonPressedFlag = false;

    Serial.println("[BUTTON] Click processed.");



    if (slot1_alarm && !slot1_taken) {

      stopBuzzerHard();

      servo1.write(50);

      slot1_lid_open_waiting = true;

      slot1_open_time = millis();

      slot1_alarm = false;

      slot1_taken = true;

      sendTelegramReliable(tr_taken(1));

    }



    if (slot2_alarm && !slot2_taken) {

      stopBuzzerHard();

      servo2.write(55); 

      slot2_lid_open_waiting = true;

      slot2_open_time = millis();

      slot2_alarm = false;

      slot2_taken = true;

      sendTelegramReliable(tr_taken(2));

    }



    if (!slot1_alarm && !slot2_alarm) {

      stopBuzzerHard();

      digitalWrite(LED, LOW);

    }

  }




  if (slot1_lid_open_waiting && (millis() - slot1_open_time >= 120000)) {

    servo1.write(5);

    slot1_lid_open_waiting = false;

  }

  if (slot2_lid_open_waiting && (millis() - slot2_open_time >= 120000)) {

    servo2.write(5);

    slot2_lid_open_waiting = false;

  }




  if (rtc_ok && (millis() - lastCheck >= 1000)) {

    lastCheck = millis();

    DateTime now = rtc.now();



    if (slot1_configured && now.hour() == slot1_hour && now.minute() == slot1_minute && !slot1_alarm && !slot1_taken) {

      slot1_alarm = true;

      digitalWrite(LED, HIGH);

      startBuzzer();

      sendTelegramReliable(tr_alert(1));

    }



    if (slot2_configured && now.hour() == slot2_hour && now.minute() == slot2_minute && !slot2_alarm && !slot2_taken) {

      slot2_alarm = true;

      digitalWrite(LED, HIGH);

      startBuzzer();

      sendTelegramReliable(tr_alert(2));

    }



    if (last_seen_day != now.day()) {

      if (last_seen_day != -1) {

        elapsed_days++;

        prefs.putInt("elapdays", elapsed_days);



        if (duration_days > 0 && elapsed_days >= duration_days) {

          slot1_configured = false;

          slot2_configured = false;

          prefs.putBool("s1cfg", false);

          prefs.putBool("s2cfg", false);

          pending_finished_message = true;

        }

      }

      last_seen_day = now.day();

      prefs.putInt("lastday", last_seen_day);



      slot1_alarm = false; slot2_alarm = false;

      slot1_taken = false; slot2_taken = false;

    }

  }

}

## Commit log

2026-07-05 Create ნახაზები
2026-07-05 ნახაზები
2026-07-05 Create ბლოკ დიაგრამა
2026-07-05 Create ცხრილები
2026-07-05 Create 3d მოდელი
2026-07-05 Create ბიუჯეთი
2026-07-07 Create განტის დიაგრამა
2026-07-07 Create ნარმინ სეიდოვა
2026-07-07 Create აინურ ალახვერდიევა
2026-07-07 Update ნარმინ სეიდოვა
2026-07-07 Create ხამმათი აბაზოვი
2026-07-07 Update აინურ ალახვერდიევა
2026-07-08 Create ხამათი აბაზოვი
